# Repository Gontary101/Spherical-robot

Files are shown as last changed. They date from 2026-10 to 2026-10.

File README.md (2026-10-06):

# GYRA: rubber-tyred spherical robots inspired by the RT-G (Mk1 → Mk2 + learned control)

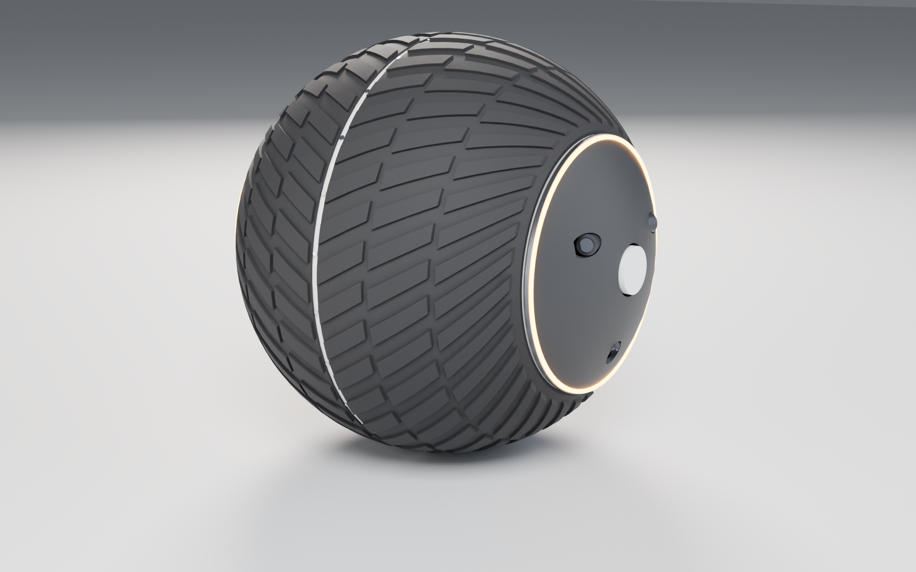
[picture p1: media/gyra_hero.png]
GYRA Mk1


This repo has three parts (the third is the Mk2 section below):

1. **A teardown of how the RT-G (Rotunbot/RotunBot) police robot actually works**, from
   the Zhejiang University paper behind it plus press and company sources:
   **[docs/01_RT-G_how_it_works.md](docs/01_RT-G_how_it_works.md)**
2. **GYRA Mk1**, a new design that keeps the RT-G's best idea (a wide rubber tyre
   rolling around a non-rotating sensor axle) and adds:
   * a **level sensor spine**, mechanically separate from the drive pendulum: the pods
     stay within 0.75° while the pendulum swings 46°;
   * a **scissored, counter-rotating CMG pair** that gives **pure roll torque**
     (stops lean-steer wobble) *or* **pure yaw torque** (turns on the spot at zero
     speed), with zero net momentum when idle;
   * an **equatorial internal ring-gear drive** (30:1) with **two anti-backlash
     pinions**;
   * a **self-locking worm lean drive** that holds a lean at zero power.

   Full spec: **[docs/02_GYRA_Mk1_design.md](docs/02_GYRA_Mk1_design.md)** ·
   simulation: **[docs/03_simulation.md](docs/03_simulation.md)** ·
   interactive 3-D viewer: **[docs/viewer/index.html](docs/viewer/index.html)**
   (open locally in a browser)

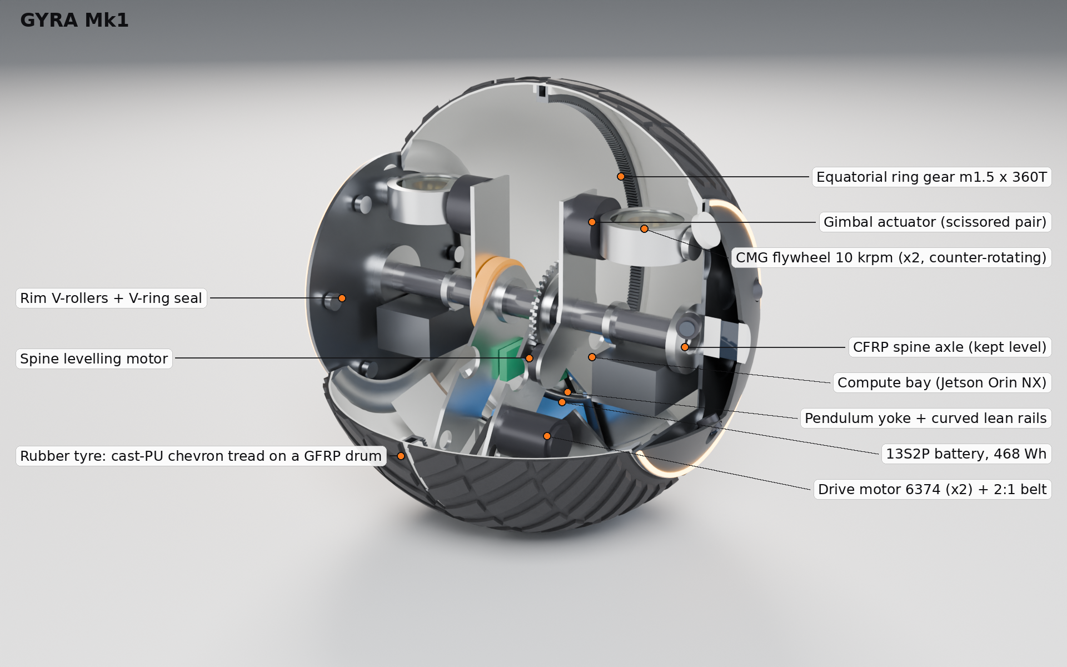
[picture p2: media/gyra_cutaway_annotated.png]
annotated cutaway


## Mk2: split differential tyre + learned control (latest)

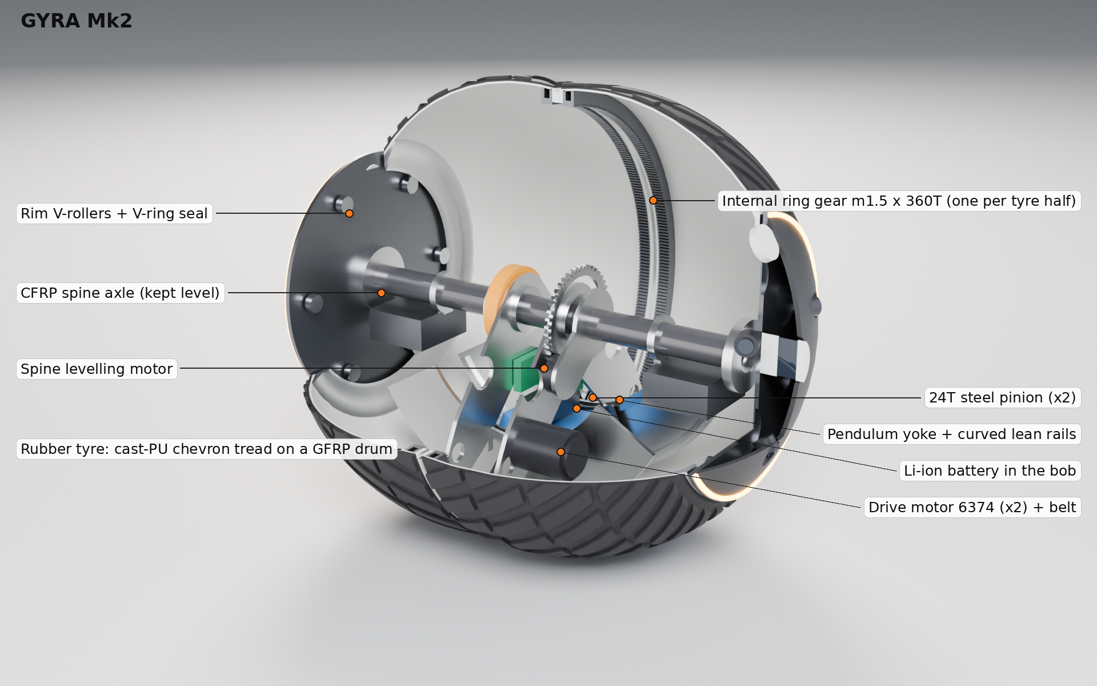
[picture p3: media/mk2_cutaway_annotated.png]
GYRA Mk2


Mk2 drops the CMGs. The tyre becomes **two independently driven halves whose crowns
are offset 50 mm outward**, so the robot stands on two contact patches and steers with
the torque *difference* between the halves. The freed mass goes into an 11 kg tungsten
+ 936 Wh bob, and the pendulum can now swing a full 360°. On top of this sit two
**asymmetric-PPO policies** trained in MuJoCo on the CAD-derived model:
* a **locomotion/teleop policy**: a residual over the classical loop, fed by IMU and
  encoders;
* an **autonomous navigator**: pod LiDARs with the real blind wedge, stereo depth,
  drifting odometry.

| | RT-G | Mk1 | **Mk2 + learned control** |
|---|---|---|---|
| turn in place | can't | 9°/s | **176°/s** (~20×) |
| 6 m/s turn at 0.6 rad/s | — | — | **stable, 7° roll** (classical loop falls) |
| falls, random commands + randomised physics + shoves | — | — | **8 %** (classical: 67 %) |
| sensor-pod pitch while accelerating | ≈ 40° | 0.75° | **0.39°** |
| grade (sim) | 10° tested | 10° | **14°** |
| battery | 2.4 kWh @ 160 kg | 468 Wh @ 41 kg | **936 Wh @ 45 kg** |
| autonomous navigation, 100 random maps | claimed | — | **79 % success, 2 % collisions, 1.35 m/s** (VFH baseline: 72 %, 11 %, 0.86 m/s) |

What does *not* get 10× better, and why (gravity-limited grade and acceleration), is
covered in [docs/04](docs/04_mk2_research_and_bounds.md). Full numbers:
[docs/07_scorecard.md](docs/07_scorecard.md) · design: [docs/05](docs/05_GYRA_Mk2_design.md) ·
learning: [docs/06](docs/06_learned_control.md) · 3-D viewer: [docs/viewer/mk2.html](docs/viewer/mk2.html)

| Learned locomotion vs classical | Mk2 classical benchmark |
|---|---|
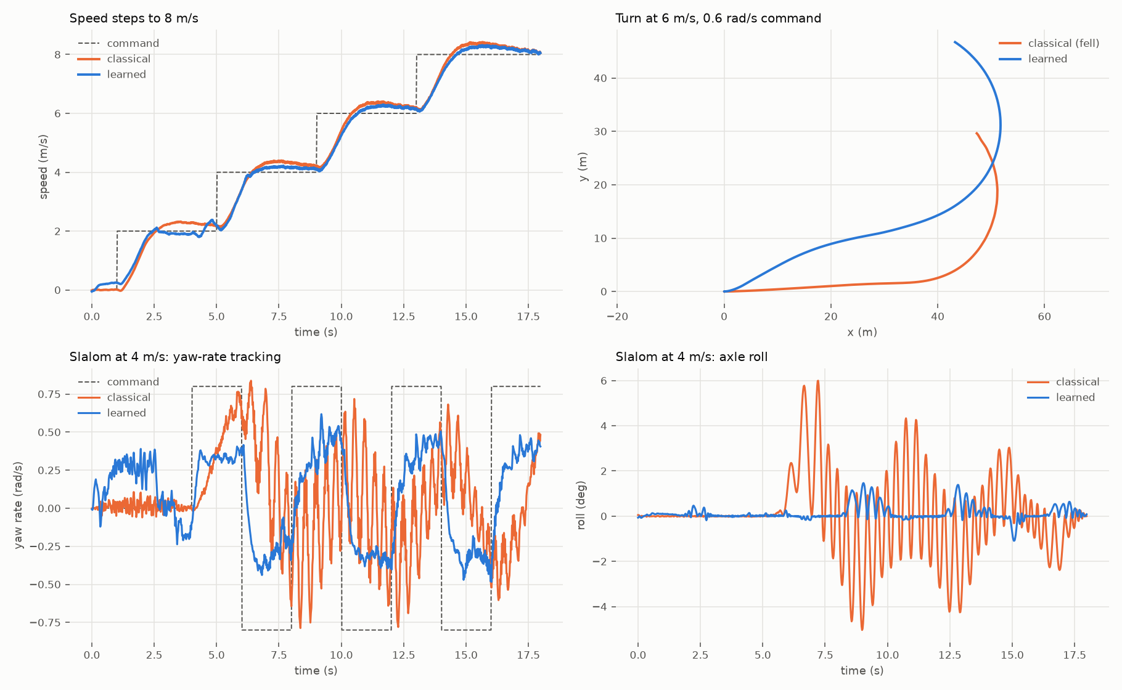
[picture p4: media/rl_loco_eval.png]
rl
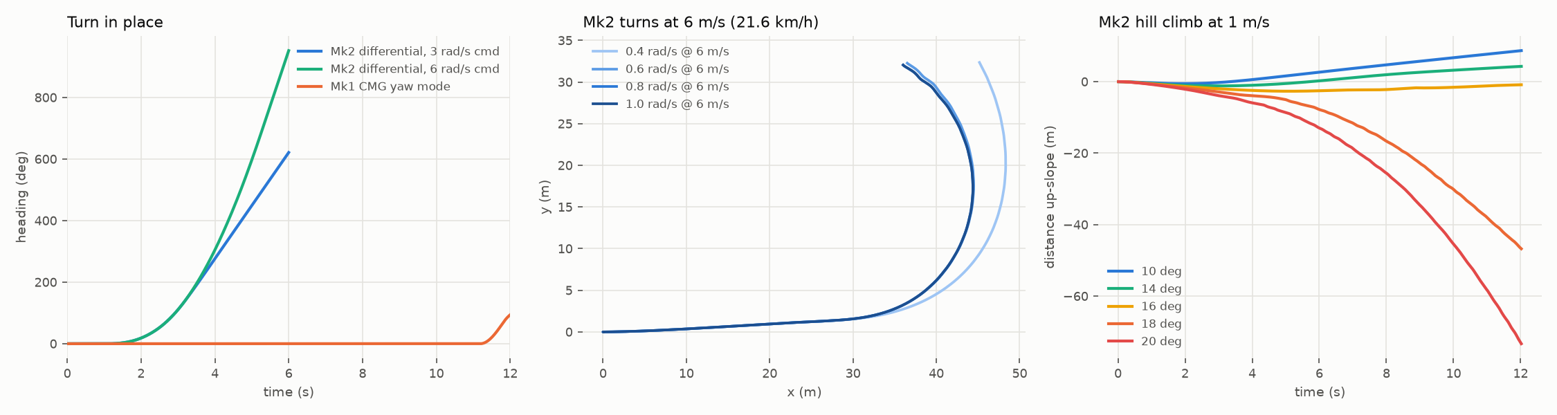
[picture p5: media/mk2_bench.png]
mk2
|  |  |

---

## The short version of "how RT-G works"

* The **central rubber shell** (fibre-reinforced rubber with a tread, 27.6 kg) is the
  only part that rolls. **The side pods are bolted to the main shaft**, so cameras,
  LiDAR and GNSS see out directly; there's no transparent hull.
* A motor on the internal frame turns the shell. Its reaction torque **lifts a 73 kg
  pendulum** (battery inside), and gravity does the driving. Grade and acceleration are
  limited by m·g·L of the pendulum, not by the motor.
* **Steering = leaning.** A second motor swings the pendulum sideways. The spinning
  shell precesses toward the low side, like a rolling coin, so the turn radius grows
  with v².
* A **42 cm momentum wheel** with its axis along the direction of travel only damps
  roll wobble. That's what let the RT-G reach 10 m/s.
* Correction to the "axis stays stable" idea: the pods are held level only by gravity,
  and **they pitch with the pendulum** when the robot accelerates, brakes or climbs.
  GYRA fixes this.

## GYRA Mk1 at a glance (all derived from the CAD model)

| | | | |
|---|---|---|---|
| Diameter | **600 mm** | Mass | **41.4 kg** (CoM 59 mm below centre) |
| Top speed | **6.4 m/s** (23 km/h) | Drive | 2 × 6374 BLDC → belt → ring gear, **30:1** |
| Grade | **10°** demonstrated in sim (13.6° static) | Lean torque | **11.2 N·m** sustained, + **18.5 N·m** CMG burst |
| Turn radius | 1.3 m @ 1 m/s · 5.8 m @ 2 m/s (sim) | Turn in place | **yes** (CMG yaw mode) |
| Sensors | 2 × Livox Mid-360, 6 × GS cameras (0.56 m stereo baseline), dual-antenna RTK | Compute | Jetson Orin NX 16 GB |
| Battery | 468 Wh, ~4 h / 45 km @ 3 m/s | Water | floats at 41 % draft, chevron tread paddles |
| Parts | 89 | Interferences | **0 across 45 mechanism poses** (B-rep check) |

| Exploded | Section through the drive plane |
|---|---|
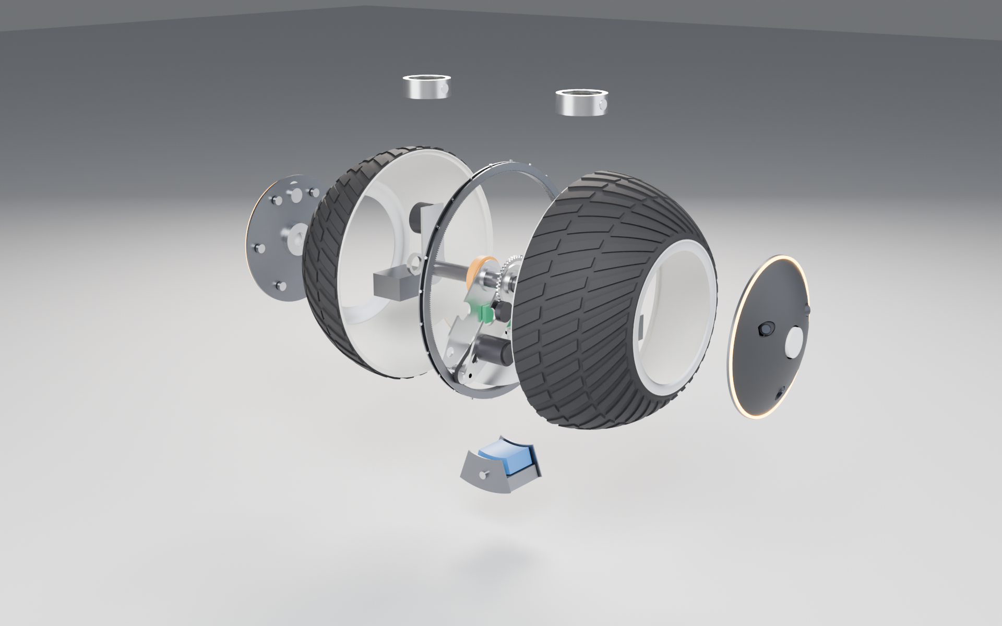
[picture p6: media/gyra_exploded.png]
exploded
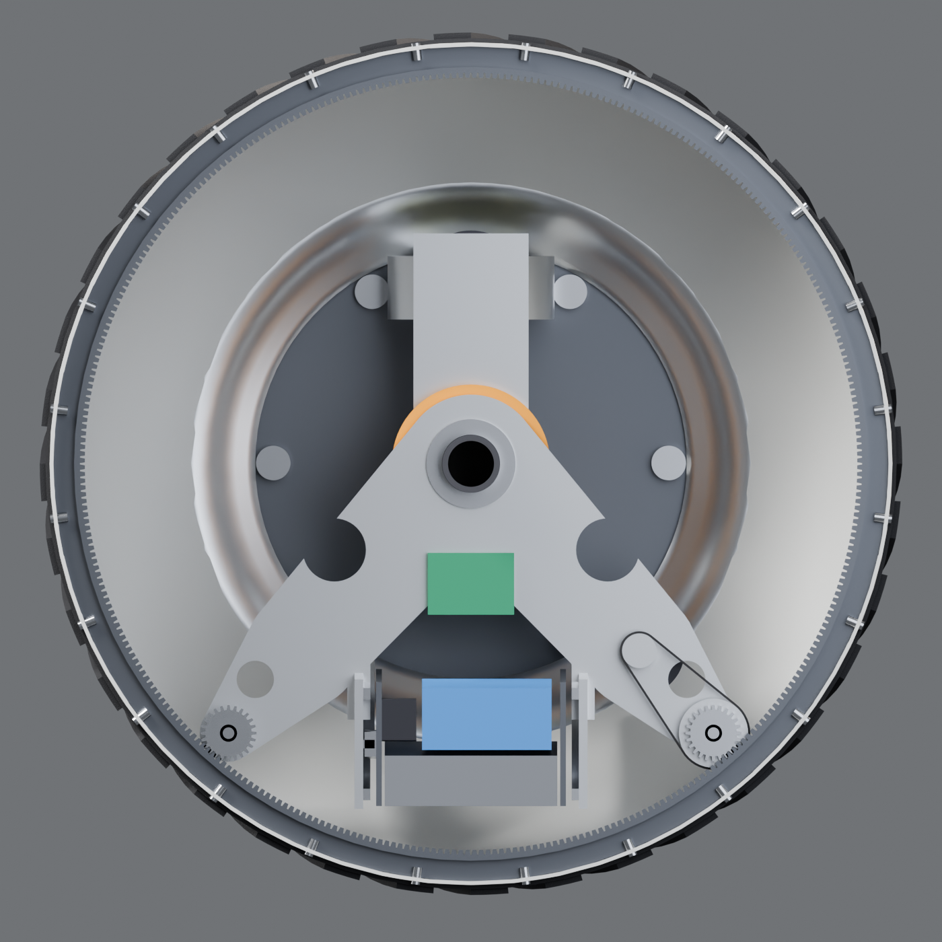
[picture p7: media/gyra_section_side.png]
section
|  |  |
| **Leaning into a turn** | **X-ray** |
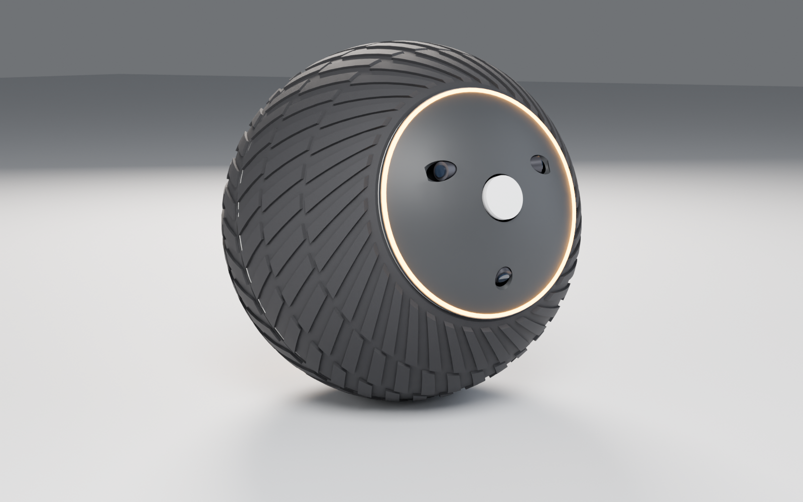
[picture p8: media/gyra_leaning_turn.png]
lean
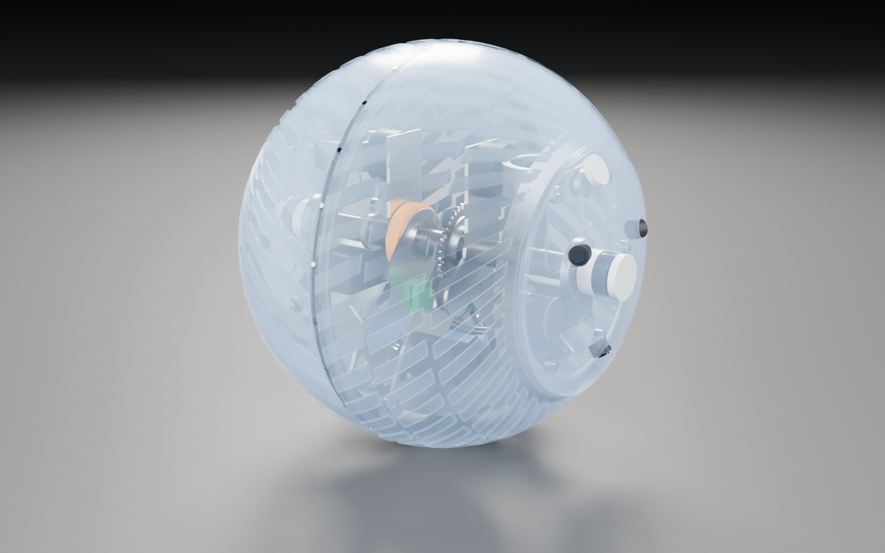
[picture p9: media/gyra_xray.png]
xray
|  |  |

### Simulation highlights (MuJoCo, model generated from the CAD inertias)
| Lean-steer at 2 m/s: CMG off vs on | Turn in place at zero speed |
|---|---|
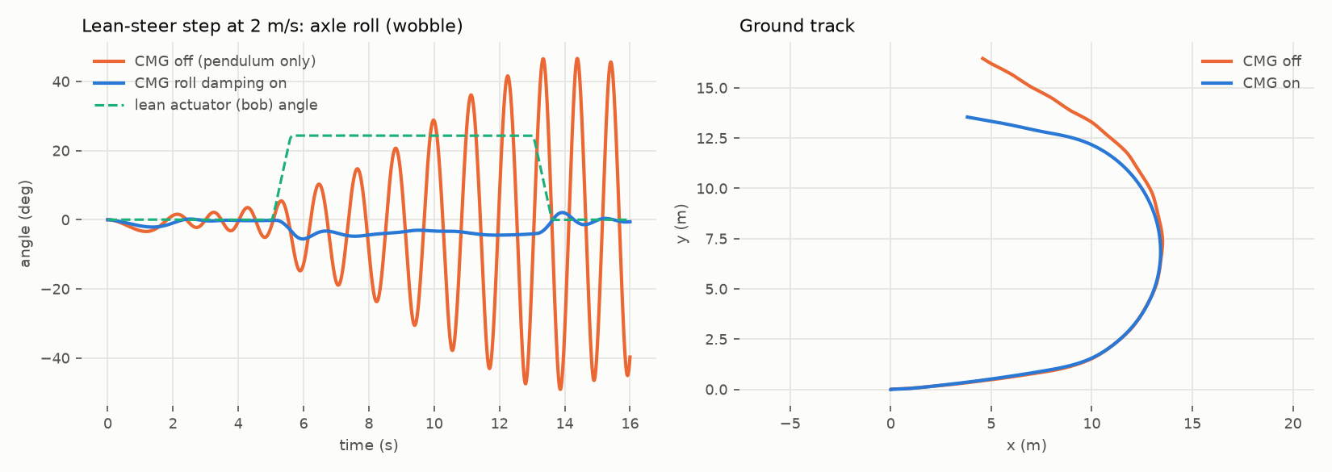
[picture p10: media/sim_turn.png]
turn
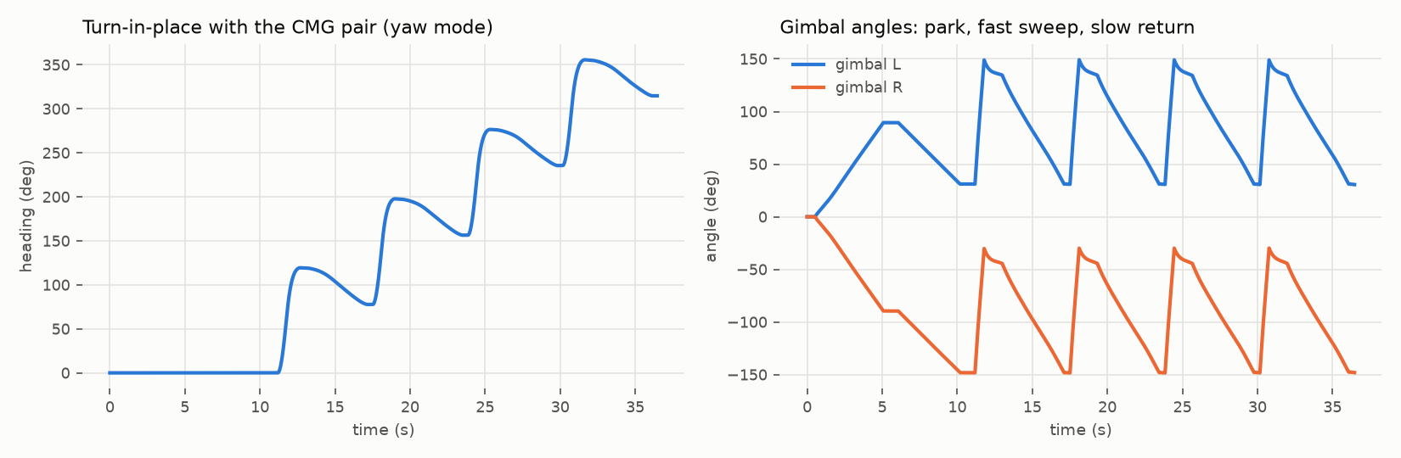
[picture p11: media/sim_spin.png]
spin
|  |  |

## Repository layout
```
cad/gyra2_cad.py         Mk2 parametric CAD (split tyre) -> cad/out2/
sim/gyra2_model.py       Mk2 MuJoCo model + motor torque-speed model
sim/gyra2_sim.py         Mk2 classical controller + benchmark
rl/loco_env.py           locomotion env (sensor-realistic actor obs, privileged critic, domain randomisation)
rl/nav_env.py            navigation env (pod-LiDAR blind wedge, stereo depth, drifting odometry)
rl/ppo.py, vec_env.py    asymmetric PPO + subprocess vector env
rl/train_*.py, eval_*.py training + evaluation; rl/runs/{loco,nav}/ deployed policies + eval.json
calc/scorecard.py        RT-G vs Mk1 vs Mk2 table from all result files
cad/params.py            single source of truth for dimensions
cad/gyra_cad.py          parametric CadQuery model → STEP / STL / mass properties / interference check
cad/export_glb.py        → cad/out/gyra_mk1.glb
cad/out/                 gyra_mk1.step (coloured assembly), stl/, glb, mass_properties.json, interference_report.json
calc/sizing.py           closed-form sizing from the CAD mass properties → calc/out/sizing.json
sim/gyra_model.py        MJCF generator (CAD inertias → MuJoCo)
sim/scenarios.py         closed-loop experiments → sim/out/summary.json, media/sim_*.png
render/render_gyra.py    Blender Cycles renders (hero, cutaway, x-ray, exploded, sections, poses)
render/annotate.py       visibility-checked call-out labels
render/build_viewer.py   self-contained three.js viewer → docs/viewer/index.html
docs/                    research report, design spec, simulation report
```

## Reproduce
```bash
pip install cadquery mujoco numpy scipy matplotlib trimesh pillow torch
python cad/gyra_cad.py --check        # CAD, exports, mass properties, 45-pose interference check
python cad/export_glb.py
python calc/sizing.py
python sim/scenarios.py
BLENDER=/path/to/blender render/render_all.sh
python render/annotate.py media/gyra_cutaway.png media/gyra_cutaway_annotated.png
python render/build_viewer.py            # Mk1 viewer;  `mk2` for the Mk2 viewer
# Mk2 + learned control
python cad/gyra2_cad.py --check && python cad/export_glb.py out2
python sim/gyra2_sim.py
python rl/train_loco.py --steps 4e6 && python rl/eval_loco.py
python rl/train_nav.py --loco rl/runs/loco/best.pt --steps 7e5 && python rl/eval_nav.py
python calc/scorecard.py
```
Tested with CadQuery 2.8 / OCCT 7.9, MuJoCo 3.15, Blender 4.2 LTS.

## Status
Mk1 is a **concept-level CAD and simulation design**, not yet built. Gears use
trapezoidal tooth approximations. Purchased parts are modelled as envelopes with their
real masses. The main open items are in §7 of the design doc: grade capability, seal
validation and flywheel spin-down/burst testing.

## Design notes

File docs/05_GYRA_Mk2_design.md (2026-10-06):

# GYRA Mk2: split tyre, differential drive, learned control

Mk2 follows from the analysis in [`04_mk2_research_and_bounds.md`](04_mk2_research_and_bounds.md).
It drops the CMG pair and splits the tyre into two independently driven halves with
outward-offset crowns. The freed mass becomes a tungsten + battery bob. Everything
below is generated: CAD → mass properties → MuJoCo model → controllers/policies.

| | |
|---|---|
| CAD | `cad/gyra2_cad.py` → `cad/out2/` (STEP, STL, mass properties, interference report) |
| Physics model | `sim/gyra2_model.py` (inertias read from the CAD), motor torque-speed model |
| Classical baseline | `sim/gyra2_sim.py` |
| Learned control | `rl/` (asymmetric PPO), see [`06_learned_control.md`](06_learned_control.md) |

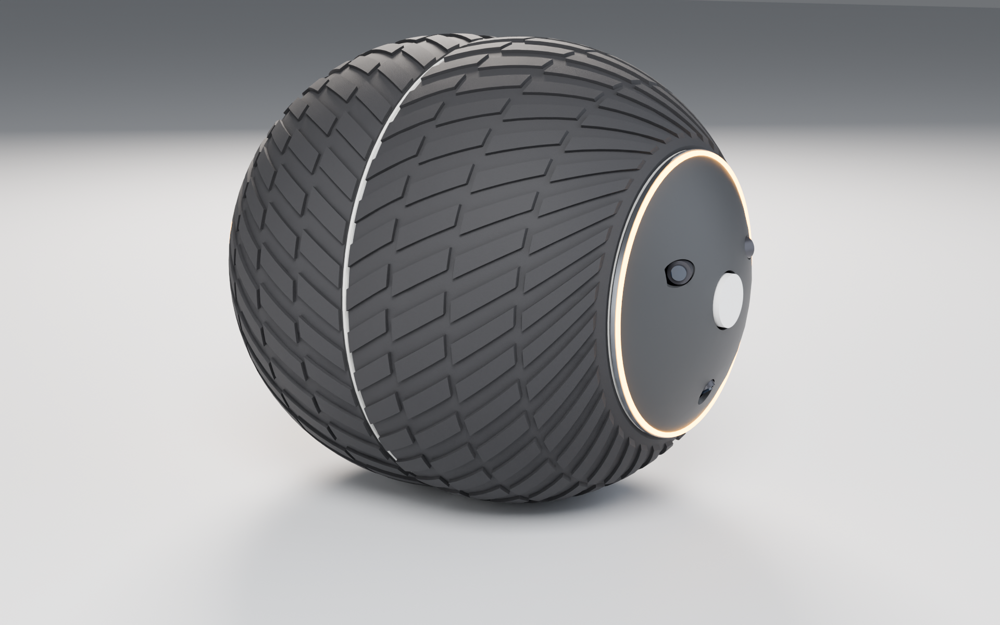
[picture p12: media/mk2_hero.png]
Mk2 hero


| Annotated cutaway | Front section (twin crowns, twin ring gears, seam slewing ring) |
|---|---|
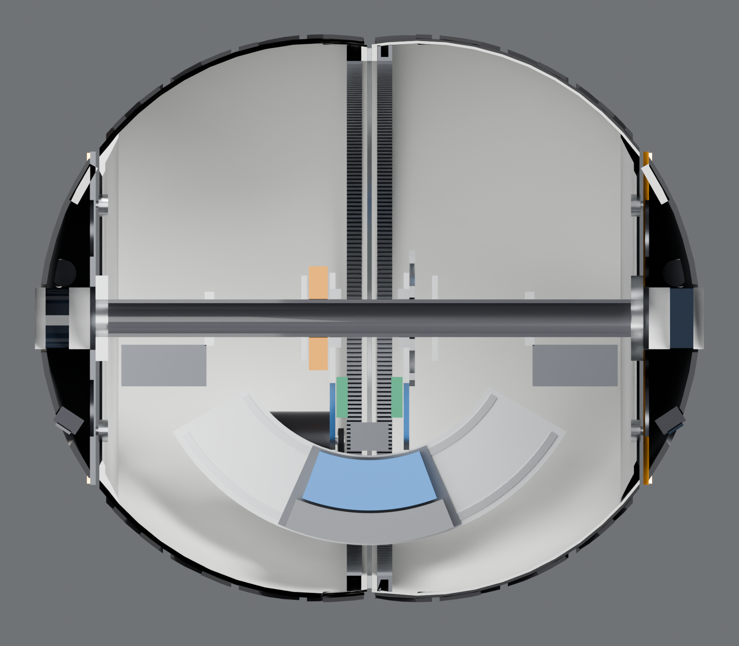
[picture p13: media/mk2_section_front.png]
section
| cutaway |  |
| **Pendulum 60°, bob 35° (driving + counter-leaning)** | **Exploded** |
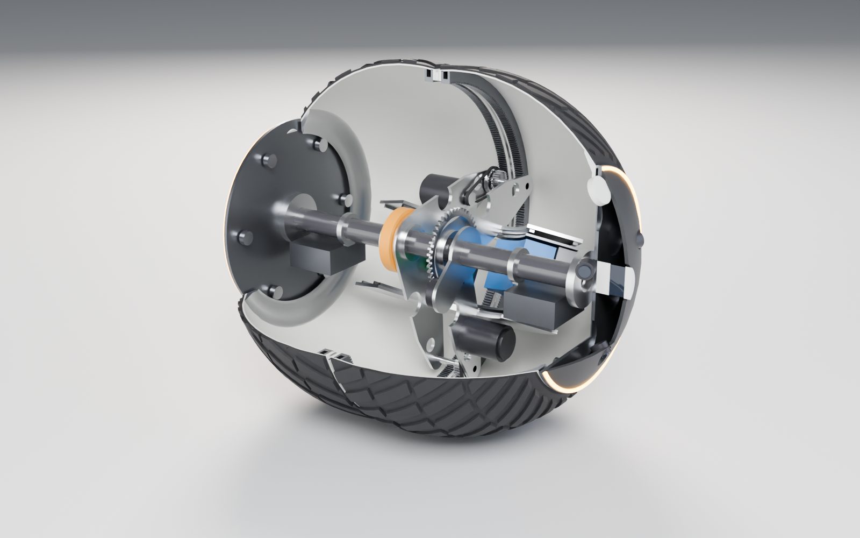
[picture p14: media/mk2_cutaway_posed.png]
posed
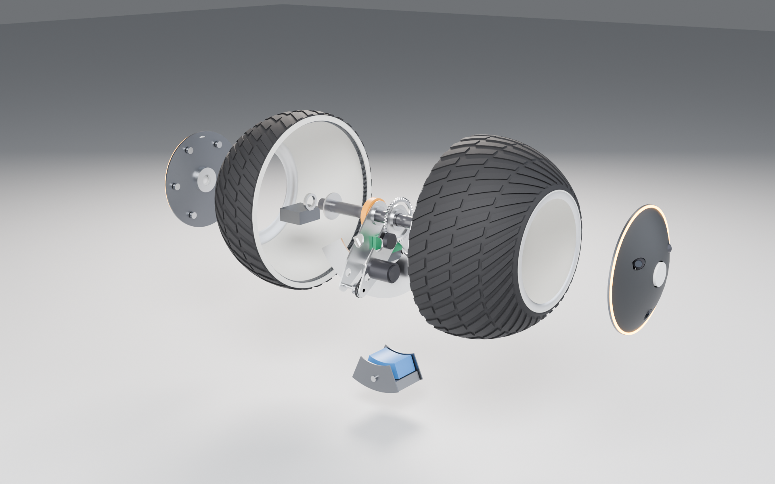
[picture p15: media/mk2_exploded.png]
exploded
|  |  |

Interactive: [`docs/viewer/mk2.html`](viewer/mk2.html).

## 1. What changed vs Mk1 and why

| | Mk1 | Mk2 | reason |
|---|---|---|---|
| Tyre | one drum, one ring gear | **two halves**, each with its own ring gear, joined by a wire-race slewing ring | differential drive: continuous yaw torque at any speed |
| Crown profile | single sphere | each half = sphere centred at y = ±50 mm → **two contact patches 100 mm apart** | passive roll stiffness M·g·d; no wobble mode at rest |
| Steering | lean + precession, CMG roll/yaw | **differential torque** + counter-lean bob | 20-40× faster spin, tighter high-speed turns |
| CMGs | 2 × 1.5 kg flywheels + 2 gimbal actuators | **removed** | twin crown handles roll and the differential handles yaw; 6.5 kg freed |
| Bob | 8.4 kg lead + 468 Wh, ±30° | **11 kg W-Ni-Fe + 936 Wh (13S4P)**, ±40° | more m·L (grade) and 2× energy |
| Pendulum travel | ±75° hard stop | **360° free**: nothing of the spine is in its swept volume | full m·g·L at 90°, no stop impacts |
| Compute | spine bay | on the pendulum (adds ballast) | better m·L |
| Drive ratio | 30:1 | **24:1** (15:1 gear × 1.6:1 belt) | 9.4 m/s no-load at 48 V |
| Width × height | 600 × 600 mm | 700 × 600 mm (each half keeps R 300) | |
| Mass | 41.4 kg | 45.1 kg | CoM 91 mm below centre (Mk1: 59 mm) |

**Interference check:** 0 collisions over pendulum pitch 0/±60/±120/180° × bob lean
0/±40°.

## 2. How the differential works with a pendulum drive

Both motors are mounted on the pendulum yoke. The front motor drives the left half,
the rear motor the right half.

* **Sum of torques** → reaction on the yoke → the pendulum swings → forward drive
  (gravity-limited: m·g·L = 39.7 N·m).
* **Difference of torques** → cancels inside the yoke (no pendulum swing) → a pure
  yaw couple (F_R − F_L)·d at the two contact patches. It is **not limited by the
  pendulum**, only by motor torque (82 N·m stall per half) and pivot friction.

## 3. Results from the physics model (classical controller)

| metric | Mk1 (sim) | **Mk2 (sim)** | gain |
|---|---|---|---|
| Turn in place, mean yaw rate | ~9°/s (CMG ratchet) | **163°/s** (3 rad/s cmd) · **258°/s** (6 rad/s cmd) | **18-29×** |
| Turn-in-place drift | 7 cm per 315° | **1 mm** | ~70× |
| Sensor pitch, 0 → 3 m/s → 0 | 0.75° | **0.39°** | 2× (≈ 120× vs RT-G-style pods) |
| Max grade (sim, 1 m/s) | 10° | **14°** (16° stalls) | 1.4× |
| Max stable speed | 6.4 m/s (motor) | **8.5 m/s** (9.0 m/s peak) | 1.3× |
| Turn radius at 6 m/s | ~48 m (lean only, predicted) | **17.9 m** with the classical loop | 2.7× |
| Battery | 468 Wh | **936 Wh** | 2× |

The classical yaw loop **oscillates at high speed**. Above roughly 0.5 rad/s at 6 m/s,
the yaw, roll and precession couplings make the hand-tuned loop diverge, even though
the tip-over bound allows about 4.5 m/s² of lateral acceleration. That is the gap the
learned locomotion policy targets.

Mk2 benchmark

## 4. Honest limits
* **Grade** stays gravity-bound: static m·L/(M·R) gives 17.4°, and 14° is
  demonstrated. No internal-drive sphere gets 10× here (see doc 04).
* **Width** grows by 100 mm. The robot is still a closed, self-righting body: lying
  on a pod, its CoM sits 92 mm off the pod sphere's centre, which rights it.
* The **forward blind wedge** of the pod LiDARs gets slightly wider (the pods move
  out by 50 mm). The centre line is seen from about 2.0 m ahead. The navigation policy
  is trained with this blind wedge modelled.

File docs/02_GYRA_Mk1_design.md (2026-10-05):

# GYRA Mk1: design specification

**GYRA** (*gyro + gyrate*) is a 600 mm, 41 kg, amphibious, rubber-tyred spherical robot.
It keeps what makes the RT-G work (a single wide rubber tyre that rolls around a
non-rotating sensor axle, driven by a pendulum) and adds four ideas the RT-G doesn't have:

1. a **level sensor spine** that is mechanically separate from the pendulum,
2. a **scissored, counter-rotating CMG pair** that does **roll** *and* **yaw**,
3. an **equatorial ring-gear drive** with dual anti-backlash pinions,
4. a **self-locking worm lean drive** (lean held at zero power) paired with the fast CMGs.

hero

---

## 1. Architecture: four coaxial bodies on one axle

```
        z ↑   x → (forward)    y ⊙ (left, along the axle)

  ┌──────────────── TYRE (rotates about y) ────────────────┐
  │ GFRP drum halves + cast-PU chevron tread               │
  │ equatorial internal ring gear m1.5 × 360T (joins halves)│
  │ aluminium rim rings with V-tracks at both edges        │
  └───────▲──────────────────────────────▲─────────────────┘
          │ 2 × 24T pinions (drive)       │ 6 V-rollers per side
  ┌───────┴───────── YOKE (pendulum) ─────┐  ┌────┴──────── SPINE (sensor axle) ────────┐
  │ hanger plates on 6908 bearings         │  │ CFRP axle Ø40 + 2 sensor pods          │
  │ 2 × 6374 BLDC → HTD belt 2:1 → pinions │◄─┤ levelling motor (spine ↔ yoke)         │
  │ cradle arc plates + curved rails/rack  │  │ CMG pair (gimbals ∥ y) + gimbal motors │
  └───────▲────────────────────────────────┘  │ compute bay, power/IMU bay, clockspring│
          │ curved rails, worm + pinion        └────────────────────────────────────────┘
  ┌───────┴──────── BOB ───────────────────┐
  │ 13S2P battery + 8.4 kg lead ballast     │   rides a ±30° arc about the x axis
  └────────────────────────────────────────┘
```

| Body | Joint (to its parent) | Mass (CAD) | CoM (mm) |
|---|---|---|---|
| Tyre | revolute **y**, on the spine's rim rollers | 11.31 kg | centre |
| Spine | — (free body) | 9.47 kg | (3, 9, 9) |
| CMG gimbals ×2 | revolute **y** at (0, ±170, 122) | 0.48 kg each | |
| Flywheels ×2 | revolute **z** (gimbal frame) | 1.50 kg each | |
| Yoke | revolute **y** on the axle (6908 bearings) | 5.74 kg | (2, 0, −129) |
| Bob | revolute **x** on the yoke's curved rails | 10.92 kg | (0, 0, −208) |
| **Robot** | | **41.39 kg** | **59 mm below centre** (self-righting) |

All masses, centres and inertia tensors come from the CadQuery model
(`cad/out/mass_properties.json`). The MuJoCo model is generated directly from them.

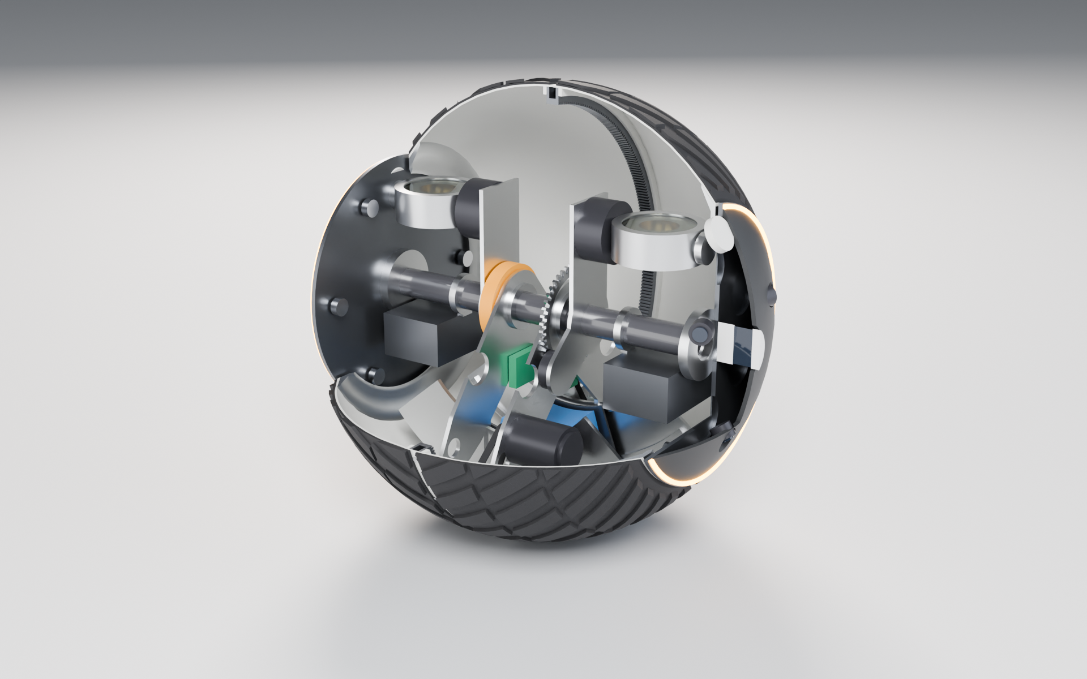
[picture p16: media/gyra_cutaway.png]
cutaway


---

## 2. The four new ideas

### 2.1 Level sensor spine (three coaxial bodies instead of two)
In the RT-G the pods are bolted to the shaft frame. The frame carries the drive motor,
so it pitches with the pendulum. In GYRA the **drive motors react against the yoke
only**. The **spine** (axle + pods + CMGs + compute) is a separate body that touches the
yoke through one small **levelling motor**. That motor holds the spine level (IMU on
the spine, PD loop), and its reaction torque goes into the heavy pendulum, which barely
notices it.

* Simulated 0 → 3 m/s → 0: the **pendulum swings to 46°**, the **sensor spine stays
  within 0.75°** (see `03_simulation.md`).
* Bonus: the levelling motor can **nod** the spine on purpose (±20°) to sweep the LiDARs
  for denser 3-D scans, or to look up stairs or down slopes.
* The spine is balanced: its CoM sits 9 mm from the axle, so the levelling torque is
  tiny (< 2 N·m in the drive test).
* Power and data cross the spine/yoke joint through a **clockspring** (flat wound
  ribbon, like a car's steering-wheel airbag reel). A hard stop at ±75° pendulum pitch
  means the reel never needs more than one turn. That's cheaper, quieter and more
  reliable than a slip ring.

### 2.2 Scissored CMG pair: one mechanism, two jobs
Two 100 mm steel ring flywheels spin in **opposite** directions at 10 000 rpm
(h = 2.31 N·m·s each, 1.2 kJ stored each) inside sealed housings. Both gimbals turn
about **axes parallel to the axle**.

**Roll mode** (spin axes near vertical). The gimbals move in opposite directions
(scissor, γ_L = +γ, γ_R = −γ):

  H = h(sin γ, 0, cos γ) + h(sin γ, 0, −cos γ) = 2h sin γ · x̂ → torque on body = −2h cos γ γ̇ · x̂

That is a **pure roll torque** of up to **18.5 N·m** at 4 rad/s gimbal rate. That's more
than the bob's whole sustained lean authority (11.2 N·m), with zero cross-coupling into
pitch or yaw. **Net stored momentum is zero at γ = 0**, so the robot does *not* behave
like a gyroscope when the CMGs are idle. A single big momentum wheel (the RT-G approach)
would add unwanted precession on every turn.

**Yaw mode** (gimbals parked at γ_L = +90°, γ_R = −90°, spin axes horizontal fore-aft,
still zero net momentum). The gimbals now sweep **together** by δ:

  H = (0, 0, −2h sin δ) → torque on body = +2h cos δ δ̇ · ẑ

That is a **pure yaw torque** of up to **18 N·m**. It beats the tyre's pivot friction
(≈ 8.5 N·m for a 35 mm contact patch), so **GYRA can spin on the spot at zero speed**.
Pendulum spheres, including the RT-G, can't do this. Each fast sweep (120°) turns the
robot about 75-110°. A slow return (torque below stiction) resets the gimbals.
Simulated: **315° in 4 cycles with 6 cm drift**.

Roll mode buys you:
* **wobble suppression**: in the sim, lean-steering at 2 m/s diverges to ±45° roll
  with the pendulum alone, versus **±0.7° with CMG damping**;
* **instant turn-in**: it cancels the "wrong-way" reaction torque you get when the bob
  starts swinging;
* **fall/kerb recovery**: a 4 N·m·s roll impulse is enough to stop a side-tip from a
  kerb strike.

Sizing and safety: flywheel ring OD 100 / ID 50 / 30 mm, 4340 steel, rim speed 52 m/s
(very low for steel, so the margin to burst is above 10×). The housings are
aluminium cans with polycarbonate inspection lids. The gimbal actuators are CubeMars
AK70-10 class (the gyroscopic load at 2 rad/s body rate is 4.6 N·m, against 8 N·m
continuous). Spin motors are about 40 W; spin-up takes about 60 s; idle drag is about
12 W per wheel.

### 2.3 Equatorial ring-gear drive
The drum is made as two GFRP halves bolted through an **internal ring gear at the
equator** (m 1.5, 360 T, Ø540 pitch, PA66-GF30 segments, I-section web). The bolts sit
in the tread's centre groove. Two **24 T steel pinions** on the yoke engage it at ±42°
from bottom dead centre. Each is driven by a **6374-class 150 KV BLDC** through a
**2:1 HTD belt**:

* overall ratio **30:1** with the final stage at the largest possible radius, so tooth
  loads are low (28.6 N·m ÷ 0.27 m ≈ 106 N at the mesh);
* two pinions **pre-loaded against each other** remove backlash (the motors apply
  opposing bias torque at standstill), so there's no clunk when the pendulum
  reverses;
* redundancy: one motor alone can still drive at full pendulum-limited torque, since
  0.53 N·m per motor is needed against 3.8 N·m peak available;
* top speed ≈ **6.4 m/s (23 km/h)** at 48 V; drive torque is pendulum-limited at
  **28.6 N·m**.

### 2.4 Worm lean drive + CMG = slow-strong / fast-light
The **bob** (13S2P battery and 8.4 kg of lead) rides **curved rails** on the yoke's
cradle along a **±30° arc about the x axis**, driven by a **self-locking worm** and a
pinion on a curved rack. It provides a **sustained lean torque of 11.2 N·m with zero
holding power**. The worm can't back-drive, so a turn costs energy only when the lean
*changes*. It is slow by design (45°/s); the CMG pair supplies the bandwidth.

---

## 3. Key numbers (from `calc/sizing.py`, all derived from CAD mass properties)

| | |
|---|---|
| Diameter / tyre width | 600 mm / 470 mm (tyre covers ±51.6° latitude) |
| Mass | 41.4 kg (tyre 11.3, pendulum 16.7, spine + CMGs 13.4) |
| CoM below centre | 59 mm (self-righting from any orientation) |
| Pendulum m·L | 3.02 kg·m (L_eff = 181 mm) |
| Max pendulum drive torque | 28.6 N·m (pitch stop 75°) |
| Drive ratio / top speed | 30:1 / **6.4 m/s (23 km/h)** |
| Max acceleration | 1.9 m/s² |
| Grade | **10° demonstrated in sim** (13.6° static limit) |
| Step | 8 mm static; ~130 mm dynamic (scaled from RotunBot's 17 cm @ R 0.4 m) |
| Sustained lean torque (bob ±30°) | 11.2 N·m |
| CMG pair roll / yaw torque | 18.5 N·m / 18 N·m (4 rad/s gimbal) |
| Turn radius (bob only) | 1.3 m @ 1 m/s · 5.3 m @ 2 m/s · 12 m @ 3 m/s · 48 m @ 6 m/s |
| Turn in place | yes, ~75-110° per CMG sweep |
| Flotation | floats with 41 % of the diameter submerged (246 mm draft), 72 kg reserve buoyancy |
| Battery / endurance | 468 Wh (13S2P 21700) / ~4.2 h, ~45 km at 3 m/s |

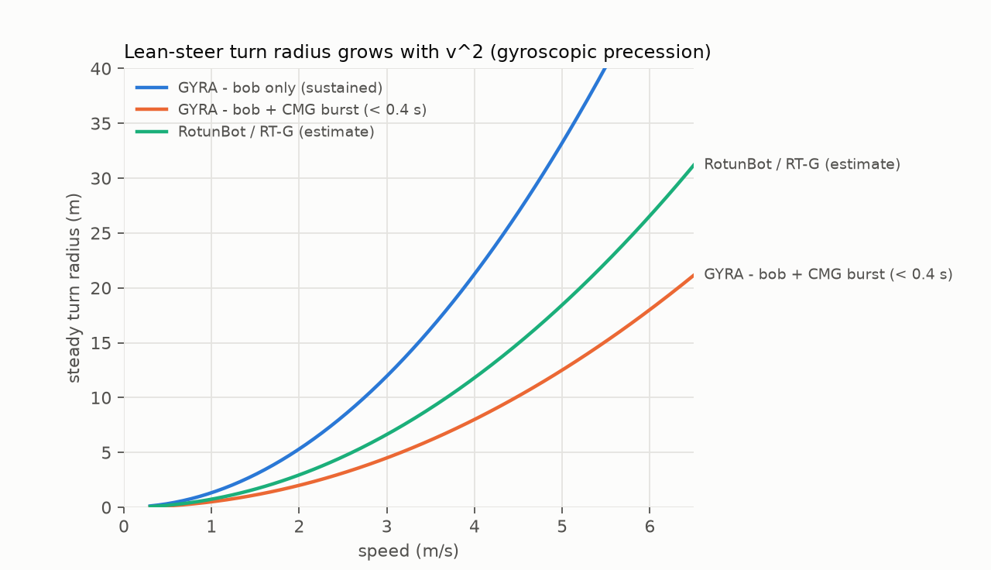
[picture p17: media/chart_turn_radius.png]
turn radius


---

## 4. Subsystem details

### Tyre
* **Drum**: two 2.5 mm GFRP spherical zones (|y| ≤ 235 mm). Each is laid up on a male
  plug and flanged at the equator for the ring gear.
* **Tread**: cast polyurethane, Shore 70A, 3 mm base + 4 mm chevron lugs (36 pitches ×
  3 rows per side, mirrored, half-pitch staggered). The chevron self-cleans mud and
  works as **paddles in water**. The 10 mm centre groove hides 24 × M5 equator bolts.
* **Rims**: 6061 rings bonded into each tyre edge, with a 90° V-track at r = 150 mm.
  Six eccentric-mounted V-rollers per pod carry the tyre (like a HepcoMotion PRT ring
  slide), so the pods can be **full rim size (Ø352)** without a huge thin-section
  bearing. A Forsheda **V-ring seal** at the 4 mm tyre/pod gap gives IP67.

### Spine
* **Axle**: CFRP tube Ø40/32, clamped into both pod plates. It carries the pendulum
  loads (≤ 1 kN dynamic).
* **Pods** (×2): 6 mm aluminium plate with lightening pockets, a 6 mm PA12 MJF shield
  (spherical cap, same R 300 as the tyre so the robot stays a sphere), and these
  sensors:
  * **Livox Mid-360** LiDAR on the axle line (360° × 59° FOV around the axle: sees
    forward, up, back and the ground on its side),
  * **3 global-shutter cameras** per pod: front (18° toe-out), rear, and ground/near-field.
    The two front cameras form a **stereo pair with a 0.56 m baseline**,
  * **u-blox ZED-F9P** antenna under a radome on each pod. With two antennas
    0.49 m apart you get **dual-antenna RTK heading**,
  * an amber **status light ring** at the pod rim.
* **Forward blind wedge**: the tyre (470 mm wide) blocks inward-looking rays. Pod
  sensors at y ≈ ±285 mm see the centreline from about 1.1-2.3 m ahead. Closer
  obstacles are tracked from the map built as they approach, and in-place yaw sweeps
  give a full look-around. (A radar *through* the non-metallic tyre is a Mk2 research
  item.)
* **Bays** below the axle (outside the pendulum's swept volume): left holds a Jetson
  Orin NX 16 GB plus carrier; right holds power distribution, a 9-axis IMU and radios.
* **Levelling motor**: pancake BLDC with a planetary reduction, pinion on a POM gear on
  the yoke hub.
* **Clockspring** on the −y side between the spine bracket and the yoke hub.

### Yoke & bob
* Hanger plates (6061, 6 mm) on 6908-2RS bearings carry both motor bosses and both
  pinion shafts. The shafts are supported at both ends.
* The cradle's arc plates (y-z sectors, ±50°) carry two curved V-rails each and one
  curved rack.
* Bob: lead casting (r 203-238 mm) plus a 13S2P 21700 pack (468 Wh) plus the worm
  gearmotor, all on a carriage with four V-rollers per side.
* The ESCs (2 × ODrive S1 class) sit on the inner faces of the hanger plates.

### Swept-volume design rule
Every pendulum part lives inside |y| ≤ 157 mm. Every spine part is either **outside**
that slab or **inside** r < 106 mm of the axle. The CMGs sit above the axle, and the
pendulum's ±75° stop keeps it out of the top sector. **`cad/gyra_cad.py --check`
verifies this with real B-rep booleans across 45 poses** (pitch −75…75°, lean ±30°,
gimbals 0 / ±90 / ∓60°): **0 interferences**.

---

## 5. Bill of materials (prototype, single unit, estimated USD)

| Item | Qty | Part / class | ≈ USD |
|---|---|---|---|
| Drive motors | 2 | 6374 150 KV outrunner | 140 |
| Drive controllers | 2 | ODrive S1 | 300 |
| Gimbal actuators | 2 | CubeMars AK70-10 | 900 |
| Levelling actuator | 1 | AK60-6 or GBM5208 + planetary | 250 |
| Flywheels + spin motors | 2 | 4340 ring (machined) + 40 W BLDC + ESC | 450 |
| LiDAR | 2 | Livox Mid-360 | 1500 |
| Cameras | 6 | IMX296 global shutter, M12 lenses | 360 |
| GNSS | 2 | u-blox ZED-F9P + patch antennas | 500 |
| Compute | 1 | Jetson Orin NX 16 GB + carrier | 900 |
| IMU | 1 | industrial 9-axis (e.g. Bosch BMI088 + mag) | 60 |
| Battery | 1 | 13S2P 21700 + smart BMS | 320 |
| Ballast | 1 | lead casting 8.4 kg | 60 |
| Tyre | 1 | GFRP drum (plug, mould, layup) + PU tread cast | 1400 |
| Ring gear | 1 | PA66-GF30, 6 segments (printed or water-jet) | 200 |
| Structure | — | water-jet 6061 plates, CFRP axle, MJF PA12 shields | 700 |
| Bearings, rollers, rails, seals, worm, belts | — | | 400 |
| Clockspring, wiring, connectors, fasteners | — | | 250 |
| **Total** | | | **≈ 8.6 k** |

## 6. Assembly sequence
1. Spine core: slide the bays, brackets, levelling motor and clockspring onto the axle.
2. Slide the yoke hub bearings on, mount the drive trains and arc plates, and fit the
   bob on its rails.
3. Mount the CMG modules on the spine brackets (inner gimbal actuators).
4. Bolt the drum halves to the ring gear around the internals (pinions mesh through
   the open rims), then torque the equator bolts from outside through the tread groove.
5. Fit the pods. The rollers engage the rim tracks, set preload with the eccentric
   pins, then bolt the pod plates to the axle flanges and fit the V-ring seals.
6. Fit the pod shields and sensors.

## 7. Risks and what Mk2 should change
* **Grade (10°)** is the weak spot of every pendulum sphere. Mk2: move the compute and
  CMGs into the pendulum, or use denser ballast (tungsten), to raise m·L/(M·R) from
  0.24 to above 0.30 (≥ 17°).
* **High-speed turn radius** grows with v². The CMG gives short bursts only. A
  speed-scheduled lean controller plus braking into corners is required.
* **Pivot stiction** sets how much of each CMG sweep is kept. Characterise it on real
  surfaces.
* **Flywheel containment** is low risk (52 m/s rim) but still needs a burst and
  spin-down test.
* **Sealing** of a 352 mm rotary joint: V-ring plus a labyrinth. Validate with a
  dunk test.

Full CAD: `cad/out/gyra_mk1.step` (89 parts, coloured) · `cad/out/gyra_mk1.glb` · `cad/out/stl/`.

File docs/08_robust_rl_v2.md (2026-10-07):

# GYRA Mk2: learned control v2, built to work anywhere

v1 (doc 06) learned to drive on flat ground with pushes, and to navigate a random-obstacle
arena. v2 rebuilds both policies and their training stack with three goals:

* hold up on any surface and under any disturbance the robot is likely to meet;
* use production-style architecture, rewards, curriculum and evaluation;
* keep simulation honest: what the robot collides with is exactly what its sensors see and
  what the renders show.

| | v1 | v2 |
|---|---|---|
| Ground | flat plane (+ gravity-tilt slopes) | procedural heightfields: hills, rough + potholes, curbs/steps/ditches, ramps to 15°, blended mixed terrain |
| World build | compiled once, obstacles moved at run time (**broken**, see §0) | **recompiled every episode** (~5 ms); obstacles are convex mesh geoms, pedestrians are mocap mesh bodies |
| Disturbances | pushes ≤ 250 N, friction 0.5-1.2 | pushes ≤ 350 N + yaw kicks, steady wind + gusts, friction 0.25-1.2 with **mid-run surface change**, payload ≤ 10 kg anywhere, tyre wear, per-motor strength 0.75-1.1, torque noise, 0-40 ms latency, IMU bias / misalignment / glitches |
| Locomotion actor | MLP on 4 frames (80 ms) | **1 s history → temporal conv encoder → latent + concurrent state estimator** → MLP |
| Losses | PPO | PPO + estimator regression + left/right **symmetry** loss; return normalisation; KL-adaptive LR with early stop |
| Curriculum | global, step-based | **per-environment** level (terrain, disturbances, speed range) moved up on clean episodes and down on falls, plus 15 % replay of easier levels |
| Navigation | 1 world type, Euclidean progress | 5 world families, pedestrians, **geodesic** progress, global-planner subgoal on a **stale prior map** (or none), sensor faults |
| Evaluation | random seeds | fixed-seed **robustness matrices** (16 locomotion, 12 navigation scenarios) against classical and v1 baselines |

## 0. A simulation bug, found and fixed

While making the video I checked that every obstacle's collision geometry matched its
rendered geometry, and found that **in v1's navigation world, obstacles never
collided**. The arena compiled 22 obstacle slots once, then moved and resized them per
episode by writing `geom_pos`/`geom_size`. MuJoCo keeps the static world body's
bounding-volume hierarchy and each geom's AABB from compile time. The broad phase
therefore never paired the tyres with a moved obstacle, and contacts were silently
missed. Only the walls, which never move, registered.

Consequences and fix:

* v1's reported navigation collision rate (2 %) only counted walls. The v1 numbers in
  doc 06 are wrong and are restated below, measured in the corrected world.
* Updating the AABBs alone is not enough (8 117 of 15 792 probe states still
  disagreed): the world-body BVH is also stale.
* v2 compiles a fresh world every episode (5 ms). Every static obstacle and wall is a
  convex mesh geom at its real pose, and moving obstacles are mocap bodies. MuJoCo
  collides convex meshes as their convex hull. All obstacles are convex and every
  input vertex is kept (asserted), so the collision shape is the mesh itself.
* The renderer builds every obstacle, wall, pole, pedestrian and the terrain from the
  geometry read back from the compiled model. It then re-casts 4 000 MuJoCo probe rays
  in Blender. Test mission: **max disagreement 0.11 mm over 3 830 rays** (float32
  rounding).
* Terrain lookups (`sim/terrain.height_at`) reproduce MuJoCo's heightfield vertex grid
  and triangulation exactly: max |ray − lookup| = 0.005 mm.

## 1. Locomotion v2

### World and robot randomisation (per episode, scaled by the env's curriculum level k)
| | range at k = 1 |
|---|---|
| terrain | 20 % flat, else one of hills (p95 slope 12°), rough + potholes, curbs/steps to 6 cm and ditches, ramps to 15°, smoothly blended mix |
| incline | 0-14° uniform slope in 40 % of episodes |
| friction | μ 0.25-1.2; 30 % of episodes switch surface mid-run (e.g. asphalt → ice) |
| robot | link masses ±10 %, CoM ±6 mm, payload 0-10 kg anywhere on the spine, tyre radius −1.5/+1 % |
| actuators | per-motor strength 0.75-1.1, 5 % torque noise, bob worm-drive 45-75°/s, latency 0-2 steps |
| pushes | 1 every 3 s on average, 50-350 N for 60-300 ms, with yaw kicks to ±40 N·m |
| wind | 0-40 N steady + Ornstein-Uhlenbeck gusts (σ 10 N, τ 1 s) |
| IMU | gyro noise 0.02 rad/s + bias to ±0.03 rad/s, mounting error to ±1.5°, rare glitch frames |
| operator | steps or 0.5-1.5 s ramps every 1.5-5 s: stop, spin, straight, arcs (lateral accel ≤ min(4, 0.6 μ g), 20 % unconstrained); speed range 2 → 8.5 m/s with k |

### Policy
* **Actor:** 50 × 18 proprioceptive frames (1 s) → 3-layer temporal conv → 64-d latent
  → linear **estimator** (body velocity, local slope, friction, payload, wind, motor
  strength). [current frame, command, latent, estimate] → MLP 256-128-64 → residual
  torque/bob action on top of the classical controller, with **full authority**
  (±60 N·m sum, ±60 N·m differential, ±0.5 rad bob).
* **Critic:** estimator targets + privileged state (contacts, every randomised
  parameter, push/wind forces, true attitude and rates) + a 7 × 7 terrain height scan →
  MLP 512-256-128.
* **Deployable artifact:** one TorchScript module with the observation normaliser
  folded in (`rl/runs/loco2/actor.ts`).

### Reward (final v3.1; per step, every term logged separately)
Errors are measured against the **feasible reference** (sec. 2), not the raw operator command.

| term | weight | |
|---|---|---|
| speed tracking | +1.0 · exp(−e_v²/0.25) + 0.5 · exp(−e_v²/0.01) | coarse + fine kernels |
| yaw-rate tracking | +0.75 · exp(−e_ω²/0.25) + 0.5 · exp(−e_ω²/0.01) | |
| distance / heading hold | +0.5 · exp(−E_s²/0.0025) + 0.5 · exp(−E_ψ²/0.0025) | E = leaky (0.2/s) integrals of the along-track and heading errors: a persistent bias is never free |
| steady sensor platform | +0.25 · exp(−(ω_pitch² + ω_roll²)/0.25) | camera/LiDAR stability is the robot's selling point |
| spine attitude | −1.0 θ_pitch² − 0.5 θ_roll² | level in both axes |
| residual size | −0.02 \|a\|² | deviate from the classical loop only when it pays |
| action rate, smoothness | −0.02 \|Δa\|², −0.01 \|Δ²a\|² | |
| mechanical power | −4·10⁻⁴ Σ max(τω, 0) | |
| torque saturation | −0.3 · clipped torque / stall torque | |
| pendulum slosh | −0.01 ω_pend² | |
| bob near its stop | −0.5 max(\|bob\| − 0.6, 0) | |
| failure: **pod strike** (CAD pod geometry touches the ground), pendulum loop-over, spine > 34° | −20, episode ends | |

### Results
Final policy: **v3.1** (`rl/runs/loco31/best.pt`, `actor.ts`), fine-tuned from v3 (15M steps) for 9M steps.
Robustness on the CAD-exact Mk2.1 model, 16 scenarios × 24 episodes (`rl/eval_robust.py`):

| controller / hardware | falls | mean spine tilt | speed RMSE vs feasible ref |
|---|---|---|---|
| classical, Mk2 as built | 27.7 % | 0.99° | 0.48 m/s |
| v1 policy, Mk2 | 19.5 % | 0.89° | 0.46 m/s |
| v2 policy (15M), Mk2 | 16.8 % | 0.83° | 0.37 m/s |
| classical, Mk2.1 | 12.5 % | 0.26° | 0.46 m/s |
| **v3.1 policy, Mk2.1** | **1.8 %** (7 / 384) | **0.21°** | **0.33 m/s** |

The remaining v3.1 falls: 350 N lateral pushes 12.5 % (beyond the roll capacity of the hardware: even an ideal bob
lean cannot recover a 350 N × 0.3 s side push), 12° incline 12.5 %, rough ground 4 %; 13 of 16 scenarios have none.

Low-speed precision (`rl/precision_test.py`, flat, 4 seeds), which tight-space navigation depends on:

| | classical | v3 | **v3.1** |
|---|---|---|---|
| spin in place: heading error vs command | 73° | 31° | **0.8°** |
| spin in place: displacement | 1 cm | 21 cm | 10 cm |
| creep 0.3 m/s, 10 s: heading drift | 0.4° | 27° | 13° |
| hold still 6 s: heading / displacement | 0.3° / 2 cm | 12° / 43 cm | 9° / 31 cm |
| stop from 1 m/s: overrun | 84 cm | 63 cm | 57 cm |

How v3.1 came about: navigation exposed a yaw bias in v3 (−0.08 rad/s while "holding still"). Channel isolation
showed it came entirely from the differential-torque residual (switching it off gives 0.0005 rad/s), and it went
with the bob action pinned at ±1 in a self-reinforcing lean (the policy observes its own last action, so
leaned-left and leaned-right are both stable modes that still satisfy the symmetry loss). The σ = 0.5 tracking
kernels made such small persistent errors almost free. Integrated-error terms, roll penalty and residual cost fix
spinning and stopping; the classical controller's yaw integrator still holds better at a standstill, and the navigation
layer closes the heading loop at 10 Hz anyway.

## 2. Root-cause analysis of the remaining falls (why v2 plateaued)

At 15M steps v2 had the lowest tracking error and spine tilt, but its fall rate had
stalled (9.4 % mean over 16 scenarios, versus 10.2 % for v1 and 18 % for classical).
Rather than patch scenario by scenario, every fall was instrumented
(`rl/diagnose_falls.py`) and each suspected mechanism tested in isolation.

**What the falls are.** All of them, for every controller and in all seven failing
scenarios, are sideways roll-overs. Drive-torque saturation before a fall is ~0,
so the "pendulum torque limit" hypothesis was wrong.

**Mechanism 1: the pendulum spends roll stability.** On a 12° incline (to hold
position) or when braking from 6 m/s, the pendulum swings to 45-70°. The robot's roll
stiffness comes from its low CoM (CoM drop ∝ cos θ_pendulum) plus the twin-crown
stance, and the bob's lean axis tilts with the yoke. Large pendulum angles therefore
halve both the passive roll stiffness and the bob's authority. Traces show a growing
roll oscillation (−60° → +58° within 0.5 s) at exactly those moments. Longitudinal
and lateral capability are coupled: a **stability ellipse**, not independent limits.

**Mechanism 2: the only roll actuator is too slow.** The worm-driven bob (60°/s)
needs ~0.7 s to cross its range, which is comparable to the ~2 s rocking period. It
rate-saturates and arrives half a cycle late (roll +32° while the bob is still at
−15°), pumping energy into the oscillation. The feedback sign is correct; flipping
it falls at 16°.

**Mechanism 3: the simulation's failure definition was not physical.** "Fall" was
roll > 63°, and the tyre halves were full spheres. Per the CAD, each half is a sphere
cap truncated at the pod opening, and the LiDAR pod touches the ground at ~45-48° of
roll. The sim now carries the pods' collision geometry (stacked cylinders following
the CAD radial profile; strike at 44.5°), and a pod strike ends the episode.

**Mechanism 4: the task paid the policy to fight physics.** The reward demanded exact
tracking of any operator command, including speed/turn combinations outside the
coupled envelope. Tracking them anyway is precisely what produces mechanism 1.

**Two false leads, kept for the record.**
* "Lateral capability collapses above 4 m/s" was an artefact: fast straight-line
  test runs left the 60 m terrain patch and hit the geofence. Without it, Mk2.1 turns
  at > 4 m/s² at 6 m/s with ~0° roll. Steady turning is not roll-limited; transient
  braking-while-turning is (mechanism 1).
* A roll reaction wheel looked attractive (RT-G uses one). Measured, it adds ~1 point
  over the geometric fix and introduces gyroscopic roll-yaw-pitch coupling, so it was
  not adopted.

### Fixes, each at the layer of its cause
| layer | fix | evidence |
|---|---|---|
| hardware | **Mk2.1**: twin-crown offset 50 → 90 mm (width 700 → 780 mm), bob lean actuator 60 → 180°/s (back-drivable ball-screw in place of the worm), PI spine levelling | classical controller, same scenarios: falls 26.2 % → **10.9 %**, spine tilt 1.00° → **0.28°** (`rl/hw_study.py`) |
| simulation | pod collision geometry from CAD; failure = pod strike or pendulum loop | strike at 44.5° (CAD vertex analysis: 45-48°) |
| task | reward tracks a **feasible reference**: operator command shaped by the true slope (uniform + local terrain), friction, payload, motor strength and the stability ellipse. The policy still sees the raw command | — |
| curriculum | **ADR**: nine factors (terrain, slope, friction, pushes, wind, payload, actuator faults, sensor faults, speed), each with its own range, widened at ≥ 80 % and narrowed below 50 % success on pooled boundary tests | — |
| optimisation | entropy bonus removed, policy std capped at 0.35 (the bob action's std had drifted to its 0.5 cap) | — |

Hardware study (classical controller, fall %, 16 episodes per cell):

| scenario | Mk2 | lean 180°/s | crown 90 mm | wheel 8 N·m | wheel 15 N·m | **Mk2.1** | Mk2.1 + wheel |
|---|---|---|---|---|---|---|---|
| hills | 25 | 0 | 0 | 0 | 0 | **0** | 0 |
| rough + potholes | 19 | 12 | 12 | 6 | 6 | **6** | 0 |
| ramps to 15° | 19 | 12 | 6 | 12 | 6 | **0** | 6 |
| 12° incline | 88 | 81 | 56 | 88 | 88 | **56** | 56 |
| pushes to 350 N | 69 | 50 | 31 | 56 | 50 | **12** | 6 |
| wind 40 N + gusts | 44 | 38 | 19 | 31 | 31 | **12** | 12 |
| payload 10 kg off-centre | 38 | 44 | 12 | 31 | 25 | **12** | 6 |
| flat, 8 m/s | 38 | 56 | 44 | 50 | 38 | **50** | 50 |
| everything at once | 38 | 38 | 6 | 12 | 6 | **6** | 0 |
| **mean, all 16** | 26.2 | 23.4 | 12.9 | 20.7 | 17.6 | **10.9** | 9.8 |

The remaining classical failures (12° incline, 8 m/s) are braking/climbing-while-
turning beyond the stability ellipse: the classical controller tracks the raw command.
That is the job of the feasible-reference policy below.

## 3. Navigation v2
(pending)

## 4. Robustness matrices
(pending)

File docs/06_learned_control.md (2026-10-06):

# GYRA Mk2: learned control (asymmetric PPO)

Two policies, trained in MuJoCo on the CAD-derived Mk2 model:

1. **Locomotion / teleoperation policy** (50 Hz): turns joystick commands (v, ω) into
   motor torques and a bob setpoint.
2. **Autonomous navigation policy** (10 Hz): turns pod LiDAR, stereo depth and
   odometry into (v, ω) commands for policy 1.

Both use the **asymmetric actor-critic** setup (Pinto et al., 2017). The actor only
gets signals the real robot measures, with noise and latency. The critic additionally
gets privileged simulator state. Only the actor is deployed.

Code: `rl/loco_env.py`, `rl/nav_env.py`, `rl/ppo.py`, `rl/vec_env.py`,
`rl/train_loco.py`, `rl/train_nav.py`, `rl/eval_loco.py`, `rl/eval_nav.py`.
Everything runs on CPU: 4 cores, ~2 k env-steps/s for locomotion, ~250 nav-steps/s
per core.

## 1. Locomotion policy

### Structure: residual RL over an estimator-fed classical loop
A first, fully end-to-end run plateaued: speed error ~0.6 m/s, falls ~35 % of
episodes, and exploration noise growing (log in `rl/runs/archive/loco_e2e/`). With
CPU-only compute, the faster route is **residual RL**. The classical cascade controller
(speed → pendulum angle → torque, yaw-rate → differential torque, lateral
acceleration → counter-lean) runs on *estimated* state (IMU + encoders + noise), and
the policy adds a bounded correction: ±25 N·m on the drive sum, ±25 N·m on the
differential, ±0.35 rad on the bob. The whole stack stays deployable, and learning
starts from a working controller.

### Observations
| | actor (deployable) | critic (privileged) |
|---|---|---|
| IMU | gyro (3), gravity direction (3) | true body velocity (3), yaw rate, roll, pitch |
| encoders | pendulum angle (sin, cos) + rate, both drive-motor rates, bob angle | pendulum absolute angle + rate, bob |
| controller | previous action (3), classical base action (3) | contacts L/R |
| command | v, ω | v, ω, tracking errors |
| world | — | friction (μ, torsional, rolling), mass scales (4), CoM offset (3), motor strength, gravity tilt (2), push active |
| history | 4 frames (18 each) → 74 inputs | current frame → 48 inputs |

Noise: gyro 0.02 rad/s, gravity 0.015, encoder rates 0.05 rad/s, plus 0-1 control
steps of action latency.

### Domain randomisation (per episode)
Friction 0.5-1.2 · torsional 0.008-0.025 m · rolling 0.002-0.008 m · body masses
±10 % · spine CoM ±5 mm · motor strength 0.8-1.1 · slopes up to 12° in a random
direction (curriculum) · random 50-250 N shoves (curriculum) · commands resampled
every 2-5 s (turn in place, straight, stop, mixed with |v·ω| ≤ 4 m/s²).

### Reward (per 20 ms step)
exp(−e_v²/0.5) + exp(−e_ω²/0.5) − 0.15|e_v| − 0.15|e_ω| − 0.05 ω_roll² −
0.5 max(|roll| − 0.35, 0)² − 2 θ_spine² − 0.05 Δa² − 0.02 a² − energy − pendulum
slosh; −10 on a fall (pendulum over the top, or roll > 63°).

### Curriculum
Commanded speed range 4 → 8.5 m/s, and difficulty (slope range, push rate/magnitude)
0.5 → 1.0. It advances when the smoothed tracking errors and fall rate pass the
thresholds.

## 2. Navigation policy

| | actor (deployable) | critic (privileged) |
|---|---|---|
| LiDAR | 72-beam 2-D scan × 2 frames, synthesised from both pod Mid-360s, **with the forward/rear blind wedge** (returns hidden by the tyre are dropped), 2 cm noise, 2 % dropouts | true unmasked noiseless 72-beam scan, nearest-obstacle distance |
| vision | 16 × 8 front stereo depth image (90° × 45°), noise ∝ range², < 0.35 m invalid | — |
| odometry | goal distance/bearing from encoder + gyro dead reckoning (gyro bias, wheel-radius error → drift) | true goal vector, odometry error |
| state | speed estimate, yaw rate, previous action, time | true v, ω |

Action: (v_cmd ∈ [−1, 3.5] m/s, ω_cmd ∈ ±2.5 rad/s) to the frozen locomotion policy.
Reward: 3 × progress − 0.01/step − proximity penalty − action-rate penalty, +10 on
reaching the goal (< 0.6 m), −10 on collision or fall. Worlds: a 14 × 14 m walled
arena with 8-22 random cylinders and boxes (0.25-0.9 m tall), start/goal 4-10 m apart.

Baseline: a classical **VFH-style gap follower** using the same masked scan and the
same drifting odometry, driving through the same low-level policy.

## 3. Results

### 3.1 Locomotion (deterministic tests, `rl/runs/loco/eval.json`)
Deployed policy: the residual PPO checkpoint at 3.9 M steps (`rl/runs/loco/best.pt`,
TorchScript `actor.pt` + `actor_obs_norm.json`).

| test | classical alone | **classical + learned residual** |
|---|---|---|
| **6 m/s turn, 0.6 rad/s command** | **falls** (roll 69°), RMS yaw error 1.28 rad/s | **stable**, roll 7°, RMS yaw error 0.32 rad/s, radius 18.9 m |
| 4 m/s slalom (±0.8 rad/s) | yaw error 0.85 rad/s, roll oscillation to 6° | yaw error 0.53 rad/s, roll ≤ 1.5° |
| **random commands + randomised dynamics + shoves** (12 × 21 s) | **67% falls**, abs errors 1.73 m/s / 0.83 rad/s | **8% falls**, 1.35 m/s / 0.47 rad/s |
| 300 N shove at 3 m/s, peak roll | 13.6° | 10.8° |
| turn in place, 3 rad/s command | 171°/s | 176°/s |
| speed steps 0 → 8 m/s | RMS speed error 0.77 (acceleration-limited) | 0.75 |

locomotion evaluation

**Remaining flaw:** the learned residual has a small yaw-rate bias, about 0.2 rad/s at
low speed when commanded straight. RMS yaw error on the straight speed-step test is
0.16 vs 0.03 for the
classical loop. A heading-hold term or a symmetry-augmented training batch (mirror
left/right) is the next fix.

**What didn't work (kept for the record).**
1. *End-to-end PPO* (`rl/runs/archive/loco_e2e`) plateaued at ~0.6 m/s speed error
   with ~35 % falls, and its exploration noise kept growing.
2. *Training on to 8.5 M steps* with the hardest curriculum stage (7 m/s, 10.5° slopes,
   225 N shoves) **degraded** the policy: 42 % falls on the evaluation suite, against
   8 % at 3.9 M (`rl/runs/archive/loco_residual_to_8p5M/eval_8p5M.json`). The
   deployed checkpoint was chosen by evaluation, not by training reward.

### 3.2 Autonomous navigation (100 fixed random maps, `rl/runs/nav/eval.json`)
Both navigators drive through the same deployed locomotion policy and see the same
masked LiDAR and drifting odometry.

| | VFH-style baseline | **learned (asymmetric PPO)** |
|---|---|---|
| success | 72% | **79%** |
| collisions | 11% | **2%** |
| falls | 2% | 6% |
| time to goal (successes) | 9.6 s | **6.5 s** |
| mean speed (successes) | 0.86 m/s | **1.35 m/s** |

The learned navigator has **5.5× fewer collisions** and reaches goals **1.6× faster**.
It falls more often (6%): it asks the low-level for more aggressive
manoeuvres, and some of them exceed what the locomotion policy can hold. Next step:
fine-tune the two levels jointly, or add the low-level's roll margin to the navigator's
observation.

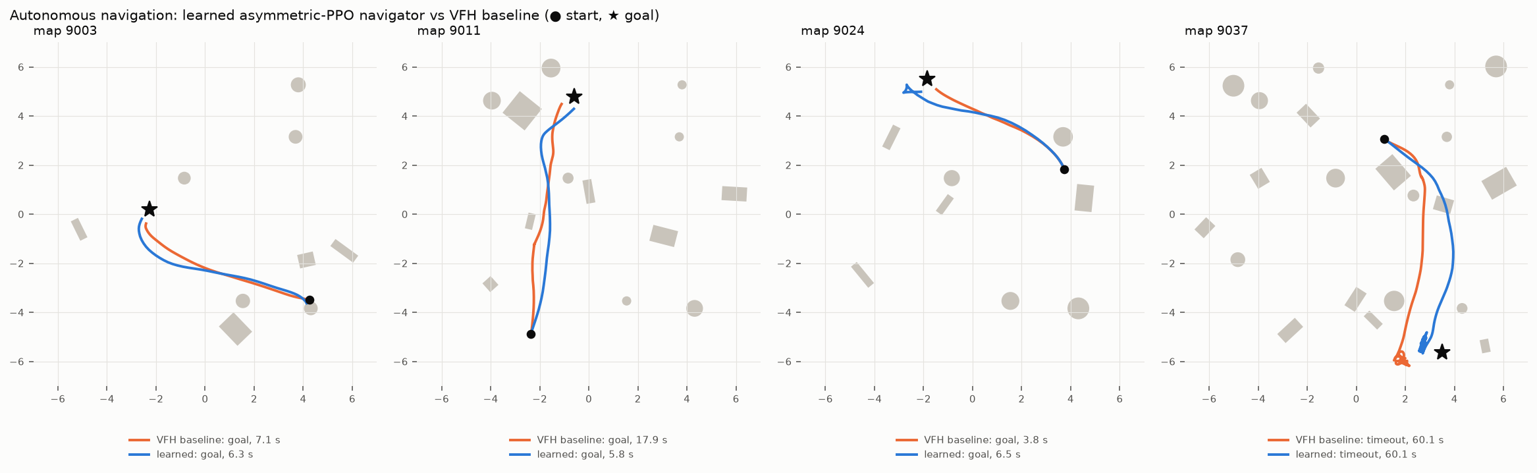
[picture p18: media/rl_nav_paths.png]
navigation paths


Example maps from the evaluation set (`rl/plot_nav.py`). On map 9037 **both**
navigators circle about 1.5 m short of the true goal. Their wheel/gyro odometry has
drifted, so they "arrive" in the odometry frame. On hardware this failure mode
disappears once the odometry is fused with the dual-antenna RTK GNSS and LiDAR SLAM.
In simulation it is the right stress test for a policy that sees only drifting odometry.

## 4. Deploying on hardware
* Run `actor.pt` (TorchScript) at 50 Hz on the Jetson. Observation = 4-frame history
  of gyro, gravity vector, pendulum/bob/drive encoders, previous action and the
  classical base action, plus the command, normalised with `actor_obs_norm.json`.
* The classical cascade runs alongside on the same estimates. The residual is added
  with the same ±25 N·m / ±25 N·m / ±0.35 rad clipping as in training.
* The levelling motor keeps its own PD loop.
* The navigator runs at 10 Hz on the Mid-360 scans (flattened to the 72-beam 2-D scan),
  the stereo depth from the two front cameras, and the wheel/gyro odometry.

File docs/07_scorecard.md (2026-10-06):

# Scorecard: RT-G vs GYRA Mk1 vs GYRA Mk2

Generated by `calc/scorecard.py` from the result files. RT-G values are published figures or
estimates from its paper's mass table using the same formulas as GYRA. All GYRA values are simulated.

| metric | RT-G / RotunBot | GYRA Mk1 | GYRA Mk2 (classical) | GYRA Mk2 (+ learned) |
|---|---|---|---|---|
| Diameter × width | 800 × 800 mm | 600 × 600 mm | 600 × 700 mm | 600 × 700 mm |
| Mass | 125-160 kg | 41.4 kg | 45.1 kg | same |
| Turn in place (mean yaw rate) | not possible (turns only while rolling) | 9°/s (CMG ratchet) | 163°/s @3 rad/s cmd · 258°/s @6 | 176°/s @3 rad/s cmd |
| Turn radius at 6 m/s | ~27 m (lean-precession estimate) | ~48 m (estimate) | 17.9 m (0.4 rad/s cmd; falls at 0.6) | 18.9 m at 0.6 rad/s cmd, no fall |
| Sensor-pod pitch, 0→3 m/s→0 | ≈ pendulum pitch (~40-46°) | 0.75° | 0.39° | same loop |
| Max grade (sim) | ~18° static est., 10° tested | 10° | 14° | 14° |
| Top stable speed | 10 m/s (paper) | 6.4 m/s (motor) | 8.5 m/s | — |
| Battery | ≈ 2.4 kWh (13S 50 Ah) | 468 Wh | 936 Wh | 936 Wh |
| Lateral shove 300 N @ 3 m/s, peak roll | — | — | 13.6° | 10.8° |
| Random commands, randomised dynamics + pushes: fall rate | — | — | 67% | 8% |
| … mean abs speed error | — | — | 1.73 m/s | 1.35 m/s |
| … mean abs yaw-rate error | — | — | 0.83 rad/s | 0.47 rad/s |
| 6 m/s turn (0.6 rad/s cmd): RMS yaw-rate err / max roll / fell | — | — | 1.28 / 69° / True | 0.32 / 7° / False |
| 4 m/s slalom (±0.8 rad/s): RMS yaw-rate err / max roll / fell | — | — | 0.85 / 6° / False | 0.53 / 1° / False |
| speed steps to 8 m/s: RMS yaw-rate err / max roll / fell | — | — | 0.03 / 0° / False | 0.16 / 0° / False |
| Autonomous nav, 100 random maps: success | L4 autonomy claimed (no data) | — | 72% (VFH baseline) | 79% (learned) |
| … collision rate | — | — | 11% | 2% |
| … mean speed on successful runs | — | — | 0.86 m/s | 1.35 m/s |

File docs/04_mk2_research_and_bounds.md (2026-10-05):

# Toward GYRA Mk2: what can get 10× better, and what physics won't allow

The goal for Mk2 is "orders of magnitude better at every aspect". This document
separates the metrics where 10× or more is physically reachable from those where a
hard physical ceiling exists, so the design effort goes where it pays.

## 1. The ceilings every internal-drive sphere hits

A closed sphere gets **no traction force except through its own shell**. Every
propulsive torque comes from an internal mass the shell pushes against. With M the
total mass, m_p and L the pendulum mass and lever arm, R the radius and θ the pendulum
swing:

| quantity | bound | Mk1 value | best realistic |
|---|---|---|---|
| grade | sin α ≤ (m_p / M)(L / R) sin θ | 13.6° (10° rated) | m_p/M → 0.6, L/R → 0.72 ⇒ **~26°** |
| acceleration | a ≤ g (m_p L)/(M_eff R) | 1.9 m/s² | ~4 m/s² |
| top speed | motor and stability, not traction | 6.4 m/s | 10-12 m/s (RotunBot ran 10 m/s) |
| static step | h = R(1 − cos α) | 8 mm | ~30 mm (kinetic: ~0.4 R) |

**Grade and acceleration cannot improve 10×.** Even an all-pendulum robot with
L = R reaches only sin α = 1. The realistic gain is about 2×, from moving everything
heavy into the pendulum (battery, compute, electronics) and pushing the pendulum's
centre of mass outward.

## 2. Where 10× *is* available

| metric | why Mk1 is weak | Mk2 lever | expected gain |
|---|---|---|---|
| **yaw rate at standstill** | CMG yaw mode is impulse-limited (2h per sweep), ~9°/s average | **split tyre, differential drive**: continuous yaw torque 2·F·d, limited only by pivot friction | **> 10×** (target > 120°/s) |
| **turn radius at speed** | lean precession: ρ = J v²/(τ R), so 48 m at 6 m/s | differential yaw torque + bob counter-lean; ρ limited by tip-over v²/(g·e/h) | **~5-8×** |
| **roll wobble** | single contact point, gyroscopic coupling | **twin-crown tyre**: two contact patches 120 mm apart give passive roll stiffness M·g·d | wobble mode suppressed without CMGs |
| **mass spent on stabilisation** | 5.9 kg of CMGs + 1 kg gimbal motors | removed: the twin crown handles roll and the differential handles yaw | −7 kg, all of it turned into battery ballast |
| **endurance** | 468 Wh | the battery *is* the ballast, so a 3× bigger pack costs no extra mass | **~3×** (≈ 13 h at 3 m/s) |
| **autonomy** | hand-tuned PD/PI loops, no navigation | learned locomotion + navigation policies (asymmetric PPO) | new capability |
| **sensor stability** | already 0.75° vs ~46° for an RT-G-style pod | keep the levelled spine | ≈ 60× vs RT-G (kept) |

## 3. The split-tyre idea in detail

Prior art. Split-hemisphere differential steering is an established family of
spherical robots: a Chinese patent on a *hemispherical differential retractable
spherical robot* (CN103387016B), and research robots with "two individually driven
semi-spheres". A 2026 *Actuators* paper (MDPI 15/4/181) decouples rolling (pendulum)
from turning with a gear-rack yaw mechanism. **What none of these combine** is a
split tyre with a **non-rotating, levelled sensor axle**, a **twin-crown rubber
profile** for passive roll stiffness, and **one pendulum reacting both drives**.

How it works:
* Each tyre half is a spherical zone whose crown is offset outward by **d = 60 mm**:
  its surface is a sphere of radius R centred at (0, ±d, 0). Upright, the robot
  stands on **two patches 120 mm apart**. The centre seam sits 6 mm below the crowns,
  so it never touches flat ground.
* Each half has its own internal ring gear and its own drive motor. Both motors react
  on the same pendulum: the **sum** of their torques swings the pendulum (forward
  drive), and the **difference** cancels inside the pendulum and appears only as a
  **yaw couple at the ground**: τ_yaw = (F_L − F_R)·d.
* Turn in place: counter-rotate the halves. Each patch rolls on a circle of radius d,
  so the only resistance is pivot friction (~8.5 N·m). Each motor needs about 28 N·m
  at the tyre for that, well inside the 6374 + 30:1 drive's 100 N·m peak, and
  **independent of the pendulum limit** because the difference torque never reaches
  the pendulum.
* High-speed turns: the turn is commanded directly by the differential, and the bob
  leans the CoM inward to stop tip-over. Lateral acceleration is limited by
  a_tip ≈ g·(d + e_bob)/h_CoM.

## 4. Learning-based control: the plan

* **Asymmetric actor-critic** (Pinto et al., 2017): the actor sees only what the real
  robot measures (IMU, motor encoders, pendulum/bob encoders, LiDAR, depth). The critic
  additionally gets privileged simulator state (true velocity, friction, masses, slope,
  obstacle map). Only the actor is deployed.
* **Locomotion / teleoperation policy**: tracks (v, ω) joystick commands at 50 Hz,
  outputting the two drive torques and the bob setpoint. It is trained with domain
  randomisation (mass, CoM offset, friction, motor strength, latency, sensor noise,
  slopes, pushes).
* **Autonomous navigation policy**: at 10 Hz it outputs (v, ω) commands to the frozen
  locomotion policy. Inputs are a 2-D scan synthesised from the two pod LiDARs, **with
  the real forward blind wedge modelled**; a low-resolution depth image from the front
  stereo pair; encoder/IMU odometry; and the goal in the odometry frame. Its critic
  sees the true pose and a local occupancy grid.
* Prior art for this structure: RL spherical-pendulum tracking with zero-shot sim-to-real
  (arXiv:2309.14096), LiDAR-ray PPO navigation on differential-drive robots, and the
  Zhejiang group's MPC trajectory tracking on the RotunBot platform (arXiv:2303.18186,
  2205.14181). RL locomotion for a **pendulum-driven sphere** appears to be unpublished.

## Sources
* Split-hemisphere patent CN103387016B: https://eureka.patsnap.com/patent-CN103387016B
* *Mechanically Decoupled Rolling and Turning Design for Pendulum-Driven Unmanned Spherical Robots*, Actuators 15(4):181: https://www.mdpi.com/2076-0825/15/4/181
* GuardBot (pendulum drive, 22 in, 25 h endurance): https://physicstoday.aip.org/news/meet-guardbot
* Pinto et al., *Asymmetric Actor Critic for Image-Based Robot Learning*: https://www.semanticscholar.org/paper/Asymmetric-Actor-Critic-for-Image-Based-Robot-Pinto-Andrychowicz/ae096b868323f74a68414ae8855e20669540e2ba
* *Tracking Control for a Spherical Pendulum via Curriculum RL*: https://arxiv.org/abs/2309.14096
* *Adaptive MPC multi-terrain trajectory tracking for mobile spherical robots*: https://arxiv.org/abs/2303.18186
* *Direction and trajectory tracking control for nonholonomic spherical robot (SMC + MPC)*: https://arxiv.org/abs/2205.14181
* *Deep RL with enhanced PPO for safe mobile robot navigation*: https://arxiv.org/abs/2405.16266

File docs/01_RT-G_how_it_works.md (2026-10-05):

# How the RT-G actually works

This is a reverse-engineering report on the **RT-G** spherical patrol robot. It is built from
the only primary technical source available, the 2025 Zhejiang University paper on the
same machine, cross-checked against press coverage and the company's own statements.

---

## 1. Who makes it

| | |
|---|---|
| Product | **RT-G** "spherical amphibious patrol robot" (police variant shown in Wenzhou, Dec 2024) |
| Company | **Logon / Luoteng Technology** (逻腾科技, also styled *Rotunbot*), Qiantang district, Hangzhou |
| Founder | **Wang You** (王酉), associate professor, Institute of Cyber-Systems & Control, Zhejiang University |
| Research name | **RotunBot**. Paper: B. Zhang, F. Zhang, H. Chen, **Y. Wang**, J. Hao (*Luoteng Hangzhou Technology*), Z. Luo, G. Li, *"A High-Speed Capable Spherical Robot"*, arXiv:2511.01288 |
| History | Development started in 2017 (planetary-exploration inspiration). Mass production started in 2023 after a second funding round. Other sizes include 60 cm and 80 cm variants. |

Published numbers don't all agree. Press articles say **125 kg**. The paper and the Hangzhou
government article say **≈160 kg**. The other figures: shell radius **40 cm** (Ø 80 cm),
**35 km/h** claimed (10 m/s measured in the paper), 0→30 km/h in 2.5 s, "withstands 4 t
impacts", **10 h** endurance (≈120 km), −45…85 °C, amphibious.

## 2. The internal architecture (from the paper's CAD figure and Table I)

```
                 external component (sensor pod)          external component (sensor pod)
                 rigidly bolted to the MAIN SHAFT          rigidly bolted to the MAIN SHAFT
                        │                                            │
   ┌────────────────────┴────────────────────────────────────────────┴────────────┐
   │  ═══════════════════════  aluminium MAIN SHAFT (spans the sphere)  ════════  │
   │      │ (1) main drive: motor on the frame → gear → FLANGE bolted to SHELL    │
   │      │ (3) momentum-wheel motor → belt → MOMENTUM WHEEL Ø420 mm, 9.8 kg      │
   │      │     (wheel axis = direction of travel → it produces ROLL torque)       │
   │      │ (2) auxiliary drive: lifts the HEAVY PENDULUM sideways (about x)       │
   │      ▼                                                                       │
   │   HEAVY PENDULUM 73.4 kg (cast steel + lead, the battery is inside it)        │
   └──────────────────────────────────────────────────────────────────────────────┘
          SHELL 27.6 kg: polyester-fibre-reinforced RUBBER with an off-road tread
```

Mass breakdown (paper, Table I). Total ≈ 160 kg, shell radius 40 cm, pendulum arm ≈ 27 cm:

| component | material | kg |
|---|---|---|
| heavy pendulum (incl. battery) | cast steel + lead blocks | 73.4 |
| spherical shell (incl. flange plate) | polyester-fibre-coated rubber | 27.6 |
| momentum wheel | cast steel | 9.8 |
| external components (both sides) | nylon shield + sensors | 15.1 |
| main shaft + everything else | aluminium alloy | 34.3 |

Electronics: 13S, 50 Ah Li-ion pack (≈2.4 kWh). An STM32F407 talks to three servo drives
over CAN at 100 Hz. An onboard computer runs navigation and SLAM over UDP. Industry
coverage adds stereo cameras with a baseline over 50 cm, mounted in the side shells
(the "insect compound eye" camera ring), plus GNSS, an IMU and motor encoders. Larger
models use an Intel i7 with an RTX 2060.

### How it drives
The **main motor sits on the internal frame** and drives a gear meshed with a **flange
that is bolted to the shell**. The motor's reaction torque has nowhere to go except into
the frame. The frame rotates forward around the shaft and lifts the 73 kg pendulum off
vertical. The centre of mass moves ahead of the contact point and gravity rolls the ball.
**Drive torque is limited by gravity × pendulum offset, not by the motor**:

  τ_max = m_p · g · L_p · sin θ  ⇒  max grade ≈ asin(m_p L_p / (M R)) ≈ 18° for the RT-G.

### How it steers ("gyro steering")
The **auxiliary motor swings the pendulum sideways**, which moves the centre of mass
laterally and tips the shaft over. The shell is spinning, so it has angular momentum
**L** along the shaft. The sideways gravity torque τ, along the direction of travel,
makes **L** precess about the vertical: dL/dt = τ. The robot **yaws toward the side it
leans to**, like a rolling coin. The turn rate is Ω = τ / L, so the turn radius grows
with v². This is why the RT-G turns tightly at walking pace but needs very wide arcs at
35 km/h. The paper sums it up: *"RotunBot completes steering tasks by moving forward and
backward while in a tilted state."*

### What the "gyroscope" really does
The **momentum wheel** (axis along the direction of travel) is a **reaction wheel for the
roll axis**. Speeding it up or slowing it down puts a roll torque on the body without
moving the centre of mass. The paper splits the job between the two actuators:

* pendulum = **roll angle** setpoint (segmented PI + model feed-forward, eq. 3: θ_ref = θ_hope + sin⁻¹(m v² tan θ_hope / (m_p g r)))
* momentum wheel = **roll rate → 0** (segmented PD)

Without the wheel, the single-pendulum ball diverges in roll above about 2 m/s when
turning and decelerating. With it, the authors report 10 m/s straight-line runs with
less than 0.05 rad roll ripple. They also cleared a 17 cm step at speed, climbed 10°
slopes, and recovered from a 0.4 rad roll kick (hitting a 10 cm brick at 4 m/s) in
under 2 s.

## 3. Your hypothesis, checked

> *"the wheel turns with a motor while the axis stays stable, so you can put LiDAR and cameras on the sides, and use a rubber wheel instead of a transparent ball"*

**Mostly right.** The details:

1. ✅ **Only the central shell rotates.** The side pods bolt to the main shaft, so they
   never spin with the tyre. Sensors look out directly, with no transparent, scratched,
   dirty or refracting hull in the way. That is also why the shell can be an opaque,
   tough, **fibre-reinforced rubber tyre with a real tread**.
2. ⚠️ **"Stable" means gravity-stabilised, not gyro-stabilised.** The shaft and pods are
   held level only by the hanging pendulum, and they are rigid with the frame that
   pitches with it. When the RT-G accelerates, brakes or climbs, **the pods pitch with
   the pendulum** (tens of degrees in a hard launch). When it leans into a turn, they
   **roll**. The "compound-eye" software de-jitters the video using IMU attitude.
3. ✅ **It turns with gyroscopic physics**, but the gyroscope is the **spinning tyre
   itself**. The momentum wheel only damps roll wobble; it doesn't steer.
4. ⚠️ It is **non-holonomic, like a unicycle**. It can't roll sideways, and it turns
   only while rolling, or with fore-and-aft shuffling.

## 4. RT-G vs. "traditional" ball robots

| | Sphero / BB-8 / hamster-ball (internal drive unit) | Omni-wheel / ballbot-in-a-ball | Classic pendulum sphere (GroundBot, Rollo, BHQ) | **RT-G / RotunBot** |
|---|---|---|---|---|
| What rotates | whole shell, any direction | whole shell, any direction | whole shell (1-2 axes) | **central tyre band only (1 axis)** |
| Drive | small car or wheels pushing the shell inside | omni-wheels on the shell inside | pendulum CoM offset | **pendulum CoM offset (geared to flange)** |
| Sensors | inside, looking through the shell (or none) | inside | inside or in transparent side domes | **in opaque side pods on the axle, direct view** |
| Shell | transparent or smooth plastic | smooth | polycarbonate | **rubber tyre with tread, 27.6 kg** |
| Steering | differential drive inside | holonomic | lateral pendulum (wobbly) | **lateral pendulum + momentum-wheel roll damping** |
| Weakness | slips, low torque | slips, complex | wobble, slow | **heavy, grade-limited, pods still pitch** |

Its closest ancestor is **GroundBot** (Rotundus, Uppsala, 60 cm, glass camera domes on
the axle ends). RT-G's real contributions are scale, a **rubber traction tyre**, a
**high-speed controller** and the **momentum wheel that separates roll stabilisation
from steering**.

## 5. What I took from this for GYRA

* Keep: sensors on the non-rotating axle ends, a rubber tyre over most of the sphere,
  pendulum drive, lean-steering, sealed amphibious body.
* Fix: (a) the pods pitch with the pendulum, (b) a single reaction wheel saturates and
  only handles roll, (c) no turn-in-place, (d) the drive gear sits at small radius on a
  side flange, (e) the lateral pendulum must hold the lean against gravity with power.

See [`02_GYRA_Mk1_design.md`](02_GYRA_Mk1_design.md).

## Sources
* Zhang, Zhang, Chen, Wang, Hao, Luo, Li, *A High-Speed Capable Spherical Robot*, arXiv:2511.01288 (Zhejiang Univ. + Luoteng Hangzhou Technology): https://arxiv.org/abs/2511.01288
* Singhal, Modi, Gupta, Vachhani, *Wobble control of a pendulum actuated spherical robot*, arXiv:2301.06433: https://arxiv.org/abs/2301.06433
* Hangzhou government news, *Hangzhou's spherical robot grabs global attention*: https://www.ehangzhou.gov.cn/2025-02/21/c_292708.htm and https://www.ehangzhou.gov.cn/2025-02/27/c_292781.htm
* 机器人大讲堂, *"大黑球"火爆全网…浙大王酉团队全面起底*: https://leaderobot.com/news/4946
* 网易, *逻腾王酉：球形机器人布局千亿市场*: https://www.163.com/dy/article/IB5HUII10511C9QL.html
* New Atlas, *Chinese police trial amphibious crime-fighting robot sphere*: https://newatlas.com/robotics/chinese-police-amphibious-robot-ball/
* Interesting Engineering: https://interestingengineering.com/innovation/chinas-spherical-robot-cop-captures-criminals
* Yanko Design: https://www.yankodesign.com/2024/12/17/rolling-crime-fighting-machine-the-futuristic-robot-redesigning-law-enforcement/
* Robots Asia product page: https://www.robotsasia.com/Rotunbot-RT-G.htm
* Rotundus GroundBot: https://newatlas.com/rotundus-groundbot/20259/ and https://orionrobots.co.uk/wiki/rotundus.html

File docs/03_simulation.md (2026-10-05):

# GYRA Mk1: physics simulation (MuJoCo 3)

`sim/gyra_model.py` generates the MJCF straight from `cad/out/mass_properties.json`.
Every body uses its CAD mass, centre of mass and full inertia tensor, so the simulation
and the CAD can't drift apart. `sim/scenarios.py` runs the closed-loop experiments
below; the numbers come from `sim/out/summary.json`.

```
python cad/gyra_cad.py      # CAD → mass properties
python sim/scenarios.py     # ≈ 10 s on a laptop, writes media/sim_*.png
```

## Model
* Kinematic tree: spine (free) → {tyre ⟂y, yoke ⟂y → bob ⟂x, cmgL ⟂y → flyL ⟂z, cmgR ⟂y → flyR ⟂z}. 13 DoF.
* Contact: tyre = sphere R 0.30 m, `condim 6` (sliding μ = 1.0, torsional 0.021 m = ⅔·μ·a for a 35 mm patch, rolling 0.006 m ≈ C_rr 0.02).
* Drive torque acts between yoke and tyre through a fixed tendon (`tyre − yoke`), so the reaction lands on the pendulum, as on the real robot. The levelling motor acts between yoke and spine.
* Flywheels spin at ±10 000 rpm under velocity servos. Gimbals are velocity servos limited to ±12 N·m. The lean drive is a stiff position servo, rate-limited to 45°/s (worm).
* 0.5 ms implicit-fast integrator, 500 Hz control.

## Controllers (all deliberately simple)
| loop | law |
|---|---|
| speed | cascade: PI(v) → pendulum swing set-point, **clamped ±65°** (never drives the pendulum over the top) → PD → drive torque |
| spine levelling | PD on spine pitch → levelling motor |
| heading hold | lean (bob) ∝ heading error − yaw rate (precession steering) |
| CMG roll mode | scissor gimbal rate γ̇ = k·ω_roll / (2h cos γ) − c·γ (roll-rate damping + centring) |
| CMG yaw mode | gimbals parked at ±90°, fast common sweep −60° → +60°, slow return |

## Results

### 1. Drive: the levelled spine works
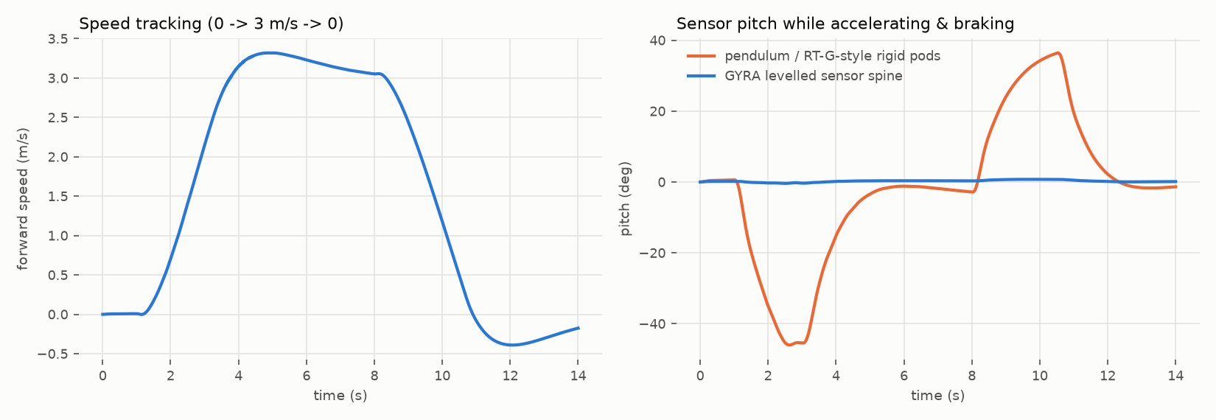
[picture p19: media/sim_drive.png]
drive


The robot runs 0 → 3 m/s → 0 (cruise 3.2 m/s). During the launch **the pendulum
(which is what an RT-G pod is bolted to) pitches 46°**. **The GYRA sensor spine peaks
at 0.75°.**

### 2. Lean-steer at 2 m/s: the CMG kills the wobble
turn

At t = 5 s the bob steps to 25° and holds:

| | roll std | roll peak-to-peak | turn radius |
|---|---|---|---|
| pendulum only (CMG off) | 24.5° | **89°**, growing | ill-defined (5.0 m mean) |
| **CMG roll damping on** | **0.48°** | **1.4°** | **5.8 m** |

Pendulum-only, the lean step excites the classic pendulum-sphere wobble mode, and at
2 m/s it grows. The RotunBot paper reports the same divergence above 2 m/s without its
momentum wheel. With the CMG pair damping roll rate, the robot settles into a clean
circle. The **simulated 5.8 m radius matches the closed-form precession estimate of
5.3 m** (`calc/sizing.py`) to within 10 %.

Note: the "off" case uses an open-loop lean step. The RT-G closes a PI loop on roll
angle with its pendulum, which helps at low speed but is limited by the pendulum's
slow, heavy dynamics. The CMG adds roll authority at a bandwidth the pendulum can't
reach.

### 3. Turn-in-place at zero speed
spin

The gimbals are first parked at ±90° (slowly, so the roll disturbance stays small).
Then each fast common sweep (−60° → +60° at 4 rad/s, about 15 N·m of yaw torque, well
above the 8.5 N·m pivot friction) spins the robot about 110°. The slow return gives
back about 35°, because the simulated rubber has finite stiction, even with MuJoCo's
no-slip solver. **Net 315° in four 6-second cycles, with 7 cm of drift.** The
closed-form estimate is ~73° net per sweep; the simulation gives ~79°.

### 4. Grades
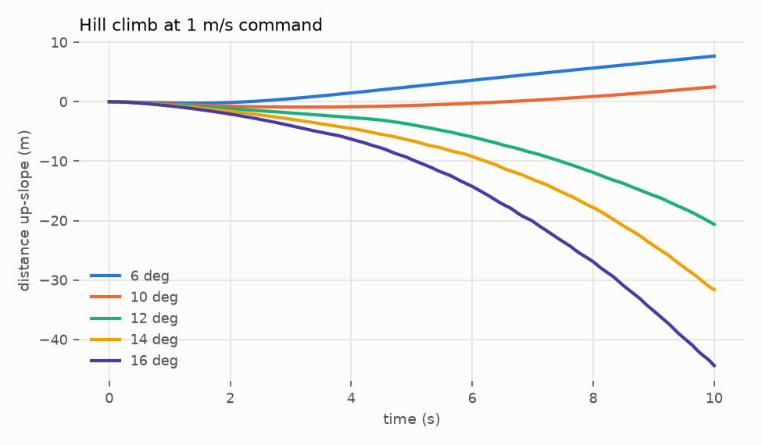
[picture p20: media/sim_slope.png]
slope


With the pendulum clamped at ±65°, the theoretical static limit is
asin(m·L·sin65°/(M·R)) ≈ 12.3°. In the simulation, GYRA climbs **6° (7.7 m in 10 s)**
and **10° (slowly)**, and slips back at 12°. **Rated grade: 10°.** This is the main
target for Mk2 (see the design doc).

## Limits of this model
* The tyre is a rigid sphere with point-contact friction. Real tread deformation, patch
  growth on soft ground, and the pods touching the ground during extreme leans aren't
  modelled.
* Motor electrical dynamics, belt compliance and gear backlash are ignored, and the
  levelling motor is ideal within ±12 N·m.
* Stiction in MuJoCo is approximate, so treat turn-in-place efficiency as an estimate
  until hardware tests.

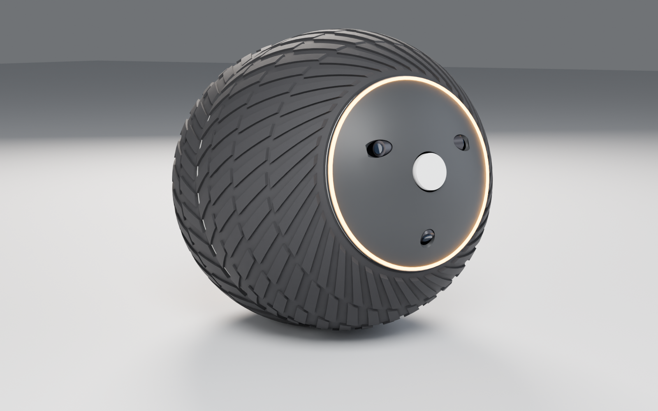
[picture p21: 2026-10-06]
media/mk2_leaning_turn.png

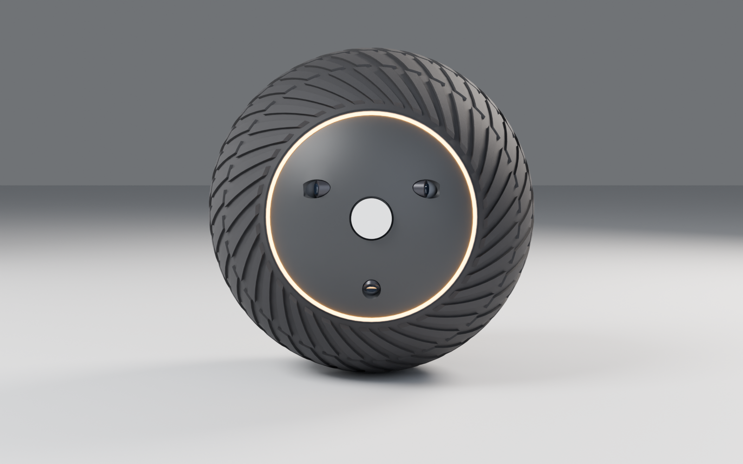
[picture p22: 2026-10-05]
media/gyra_side.png

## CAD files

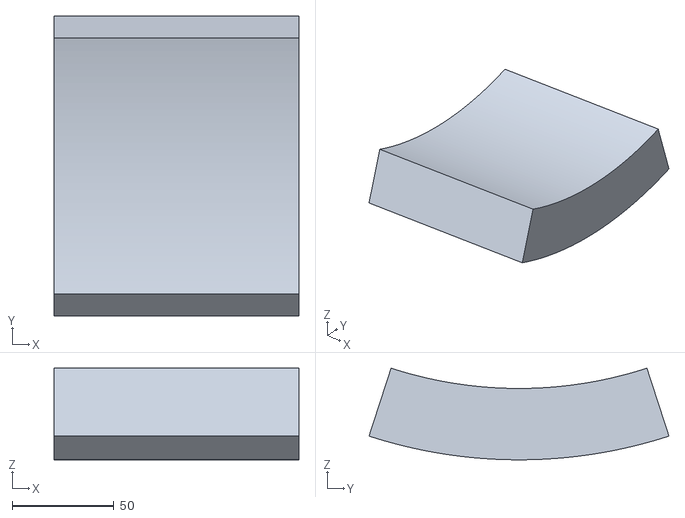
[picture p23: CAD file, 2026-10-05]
cad/out/stl/bob_lead.stl
120.0 x 147.1 x 44.9

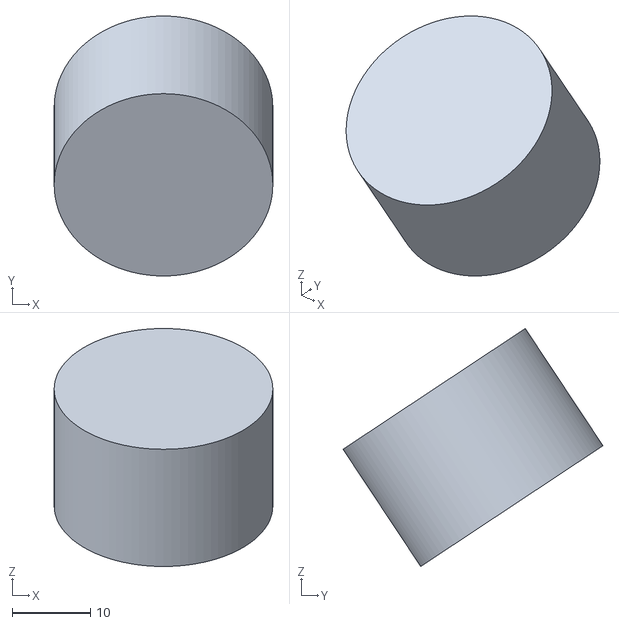
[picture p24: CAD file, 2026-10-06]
cad/out21/stl/cam2_L.stl
28.0 x 33.3 x 30.5

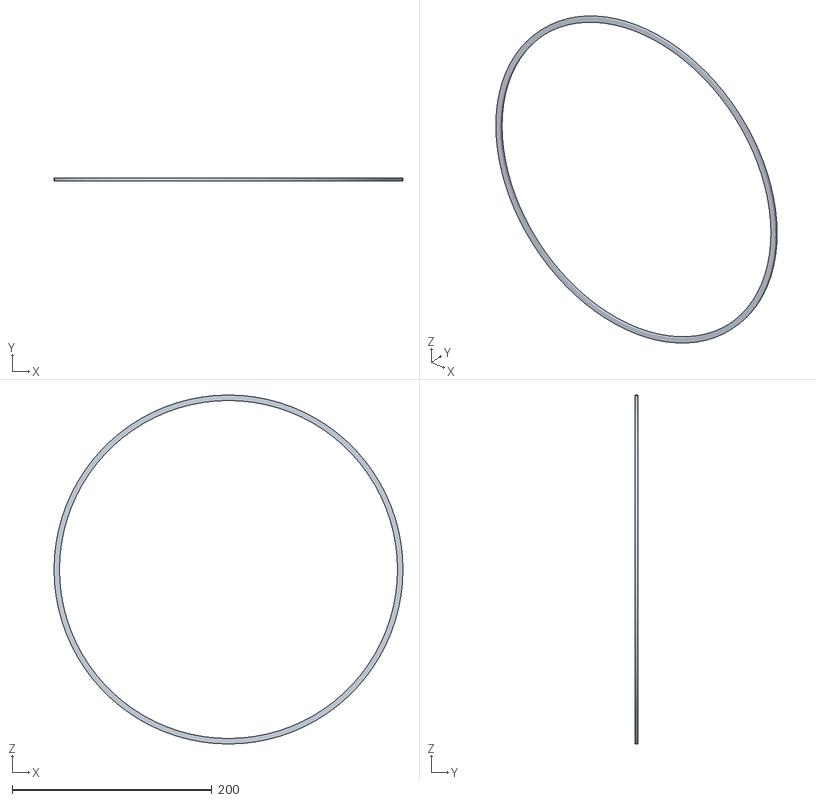
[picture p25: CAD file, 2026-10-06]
cad/out21/stl/led_ring_L.stl
349.0 x 3.00 x 349.0

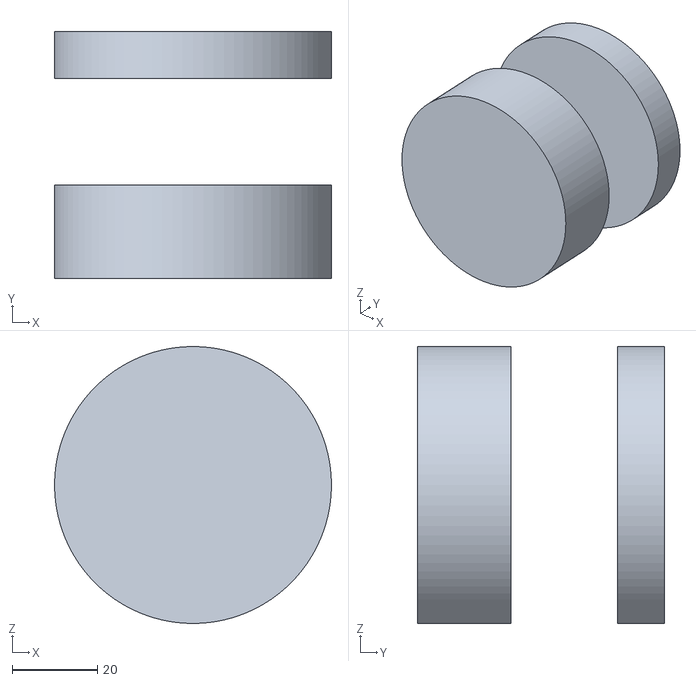
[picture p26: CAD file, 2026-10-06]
cad/out21/stl/lidar_body_L.stl
65.0 x 58.0 x 65.0

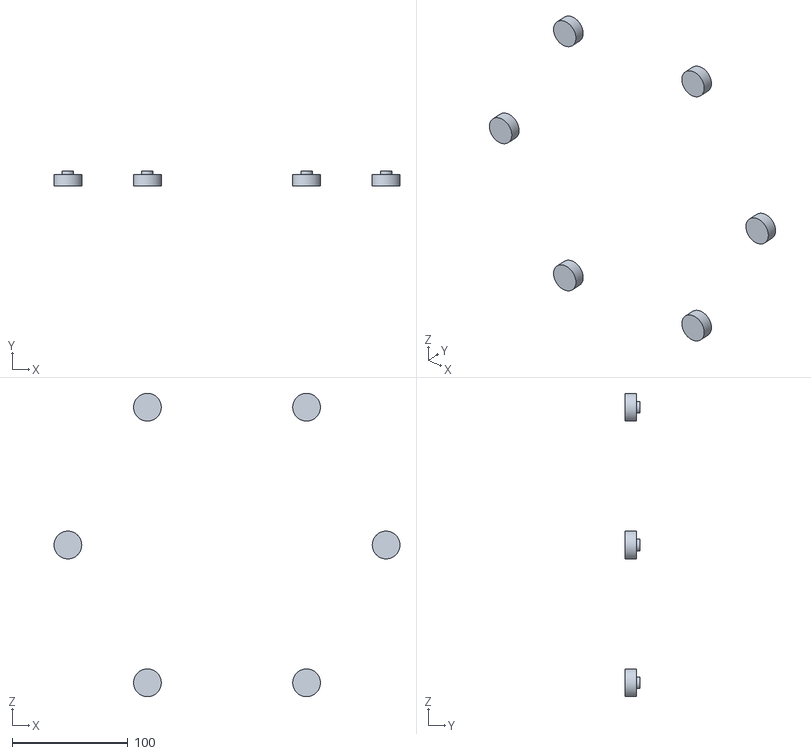
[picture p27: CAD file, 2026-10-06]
cad/out21/stl/rollers_L.stl
299.0 x 13.0 x 262.2

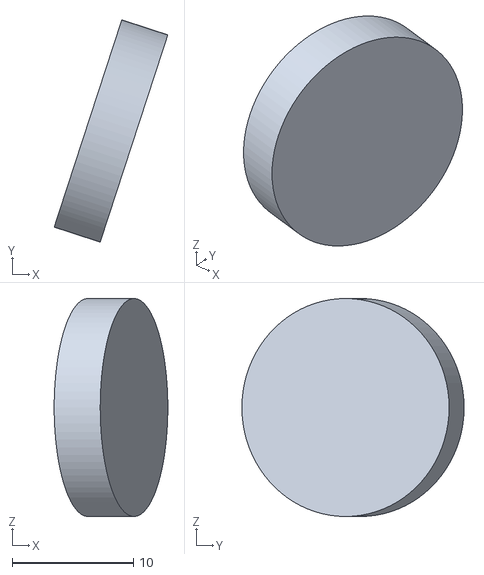
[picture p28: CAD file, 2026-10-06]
cad/out21/stl/lens0_R.stl
9.39 x 18.4 x 18.0

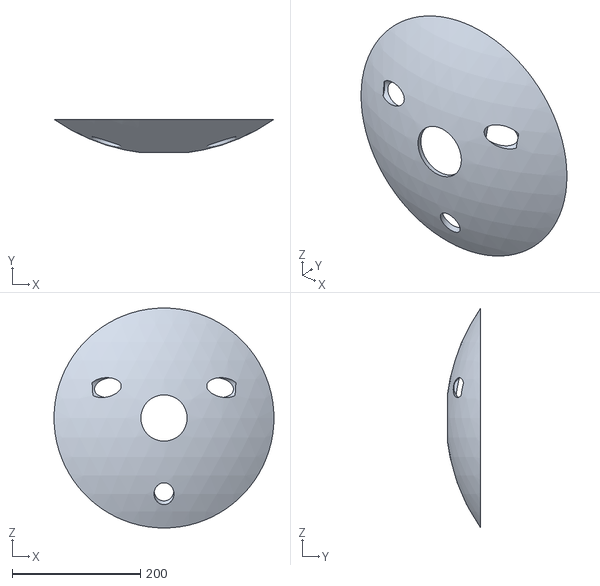
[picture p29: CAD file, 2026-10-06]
cad/out21/stl/pod_shield_R.stl
342.8 x 51.8 x 342.8

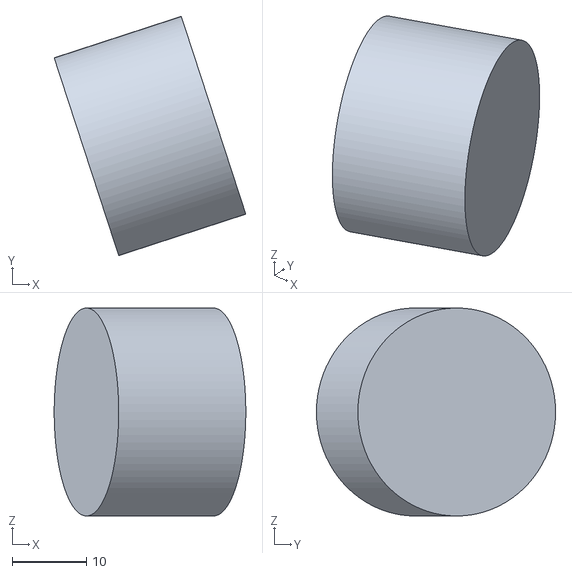
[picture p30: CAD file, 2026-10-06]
cad/out21/stl/cam0_L.stl
25.8 x 32.2 x 28.0

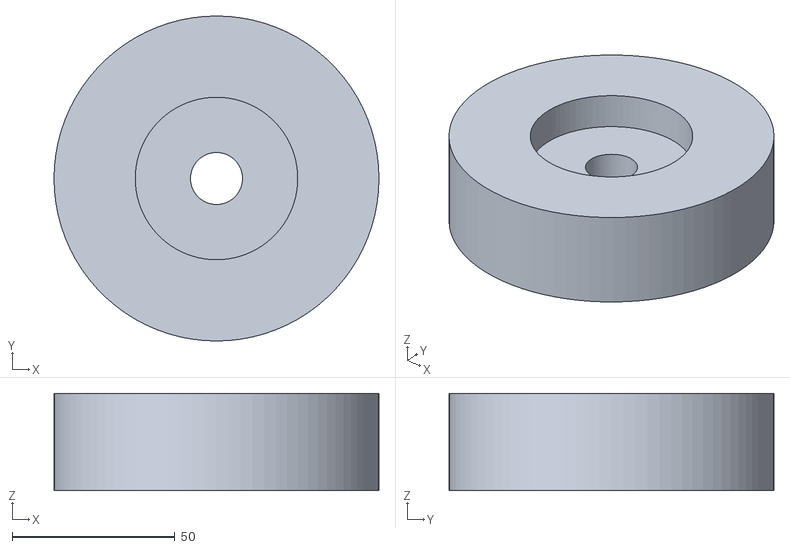
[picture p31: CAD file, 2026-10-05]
cad/out/stl/flywheel_R.stl
100.0 x 100.0 x 30.0

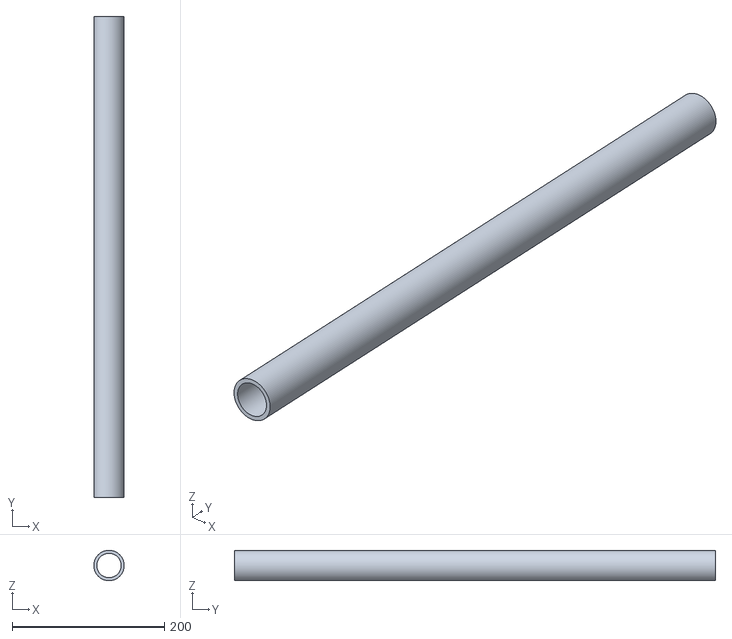
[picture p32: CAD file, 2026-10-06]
cad/out21/stl/axle.stl
40.0 x 632.0 x 40.0

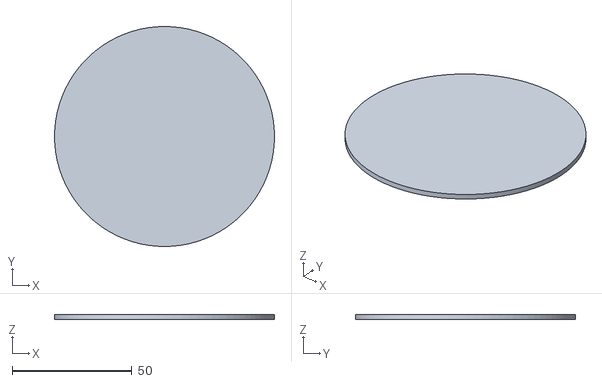
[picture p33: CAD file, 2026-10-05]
cad/out/stl/cmg_lid_L.stl
92.0 x 92.0 x 2.00

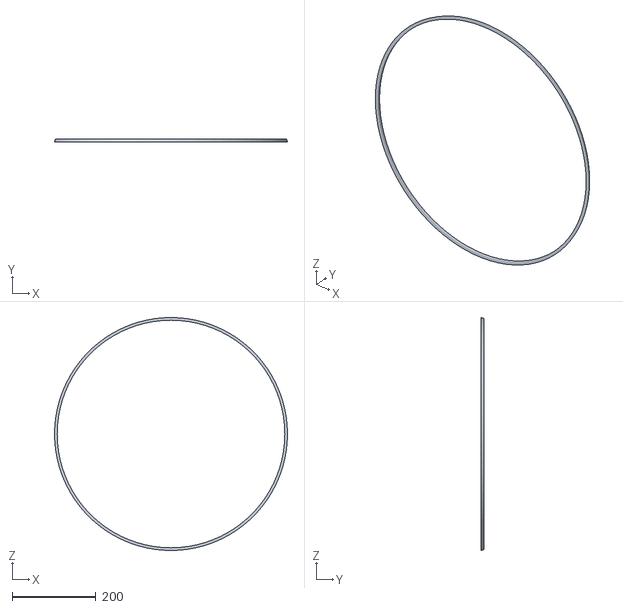
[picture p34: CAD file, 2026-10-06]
cad/out21/stl/eq_flange_R.stl
557.1 x 6.00 x 557.1

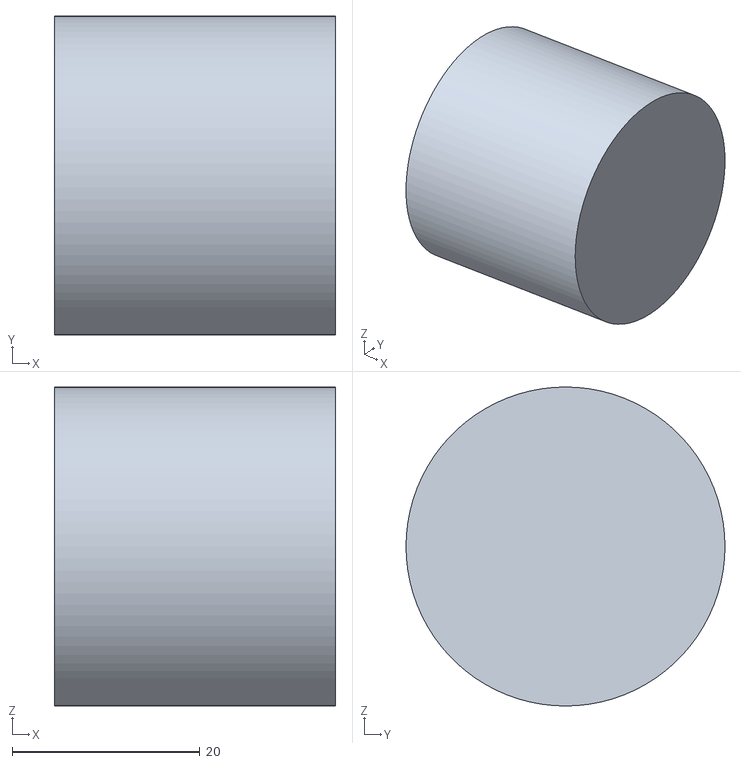
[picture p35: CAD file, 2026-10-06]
cad/out21/stl/bob_lean_drive.stl
30.0 x 34.0 x 34.0

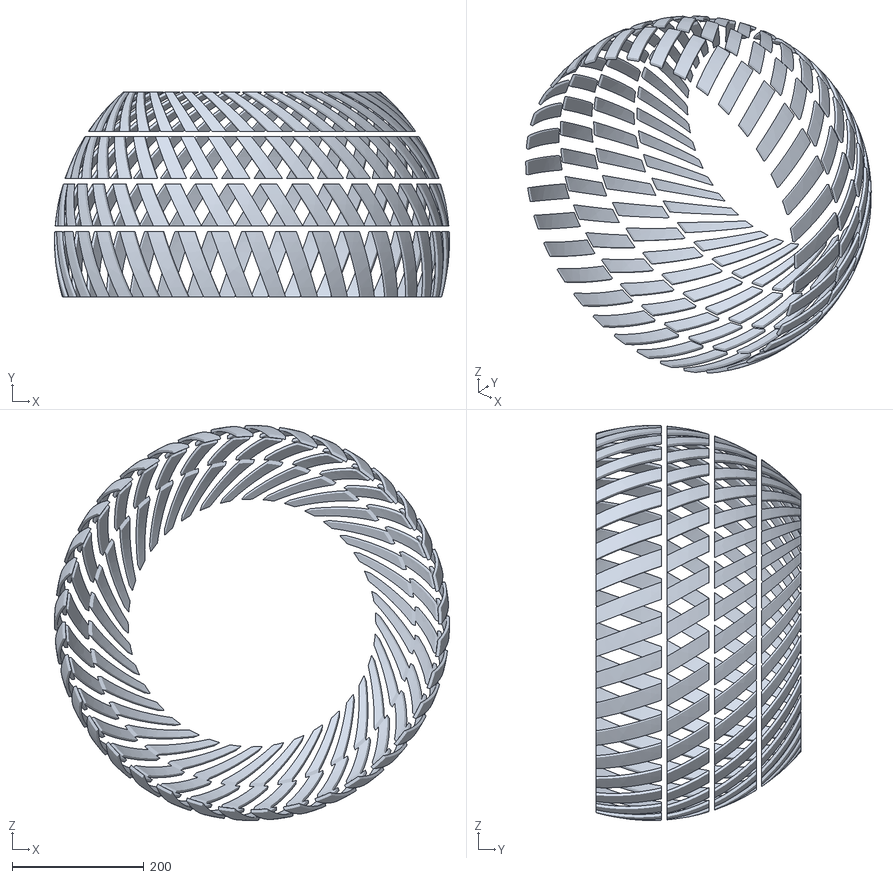
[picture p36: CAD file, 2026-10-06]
cad/out21/stl/lugs_L.stl
599.9 x 312.0 x 599.9

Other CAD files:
cad/out21/stl/lens2_R.stl
cad/out/stl/gimbal_bearing_R.stl
cad/out21/stl/led_ring_R.stl
cad/out21/stl/pod_shield_L.stl
cad/out/stl/arc_plate_B.stl
cad/out/stl/arc_plate_F.stl
cad/out/stl/axle.stl
cad/out/stl/axle_flange_L.stl
cad/out/stl/axle_flange_R.stl
cad/out/stl/bay_L.stl
cad/out/stl/bay_R.stl
cad/out/stl/bay_strut_L.stl
cad/out/stl/bay_strut_R.stl
cad/out/stl/belt_B.stl
cad/out/stl/belt_F.stl
cad/out/stl/bob_battery.stl
cad/out/stl/bob_carriage.stl
cad/out/stl/bob_rails.stl
cad/out/stl/bob_worm_motor.stl
cad/out/stl/cam0_L.stl
cad/out/stl/cam0_R.stl
cad/out/stl/cam1_L.stl
cad/out/stl/cam1_R.stl
cad/out/stl/cam2_L.stl
cad/out/stl/cam2_R.stl
cad/out/stl/cmg_housing_L.stl
cad/out/stl/cmg_housing_R.stl
cad/out/stl/cmg_lid_R.stl
cad/out/stl/cmg_spin_motor_L.stl
cad/out/stl/cmg_spin_motor_R.stl
cad/out/stl/drum_L.stl
cad/out/stl/drum_R.stl
cad/out/stl/eq_flange_L.stl
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

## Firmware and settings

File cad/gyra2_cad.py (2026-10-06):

"""
GYRA Mk2 - split twin-crown tyre with differential drive, no CMGs, 360-degree pendulum.

What changes vs Mk1 (cad/gyra_cad.py, whose helpers this file reuses):
  * the tyre is two independently driven halves. Each half is Mk1's spherical zone with its
    crown offset outward by D_CROWN, so the robot stands on two contact patches 2*D_CROWN apart
  * each half has its own internal ring gear; the front motor drives the left half, the rear
    motor the right half. Sum of torques -> pendulum swing (drive), difference -> yaw couple
  * a slewing ring at the equator lets the halves turn relative to each other
  * CMGs and gimbal actuators removed; their mass goes into a bigger tungsten + battery bob
  * nothing of the spine sits in the pendulum's swept volume -> the pendulum can swing 360 deg
  * axle, pods and bays move outward by D_CROWN

    python cad/gyra2_cad.py [--check]                 # Mk2   -> cad/out2/
    GYRA_VARIANT=mk21 python cad/gyra2_cad.py         # Mk2.1 -> cad/out21/

Mk2.1 (root-cause fix of the sideways roll-overs, docs/08 sec. 2): crown offset 50 -> 90 mm (wider stance, roll
stiffness independent of the pendulum angle) and the worm-driven bob lean replaced by a back-drivable BLDC + ball-screw
drive (60 -> 180 deg/s, so the lean no longer rate-saturates against the ~2 s rocking mode).
"""
from __future__ import annotations

import json
import math
import os
import sys
import time

import cadquery as cq
import numpy as np
from cadquery import Vector

sys.path.insert(0, os.path.dirname(__file__))
import gyra_cad as G  # noqa: E402
from gyra_cad import (Part, box, circle_pts, cyl_dir, cyl_y, extrude_xz, extrude_yz, gear_y,  # noqa: E402
                      halfspace, hull2d, mirror_x, mirror_y, revolve_y, sector_yz, slab_y, sphere, tube_y)
from params import (AXLE_HALF, AXLE_ID, AXLE_OD, CLOCKSPRING_D, CLOCKSPRING_Y, DRIVE_MOTOR_D,  # noqa: E402
                    DRIVE_MOTOR_L, DRIVE_PINION_Z, GEAR_MODULE, GEAR_R_BODY, GEAR_R_PITCH, GEAR_Z_RING,
                    LEVEL_MOTOR_D, LEVEL_MOTOR_POS, LUG_ARC_DEG, LUG_SKEW_DEG, N_LUG_PITCH, R_OUT,
                    R_SHELL_IN, R_SHELL_OUT, R_TREAD_BASE, RIM_TRACK_R, Y_EDGE)

VARIANT = os.environ.get("GYRA_VARIANT", "mk2")
OUT2 = os.path.join(os.path.dirname(__file__), "out21" if VARIANT == "mk21" else "out2")

# ---------------------------------------------------------------------------- Mk2 parameters
D_CROWN = 90.0 if VARIANT == "mk21" else 50.0   # crown offset of each half -> patches 2*D_CROWN apart
SEAM_GAP = 2.5                   # half-gap at the equator (slewing ring sits in it)
RING_Y = (8.0, 24.0)             # |y| span of each half's internal ring gear
PULLEY_Y = (26.0, 34.0)          # |y| span of the belt pulleys
ARC_HALF2 = 60.0                 # cradle arc half-angle
ARC_R2 = (145.0, 240.0)          # cradle arc radii
BOB_R2 = (147.0, 238.0)          # bob radii
BOB_HALF2 = 22.0                 # bob angular half-width
BOB_X2 = 62.0
BOB_TRAVEL2 = 40.0               # lateral travel +-40 deg
TUNGSTEN_KG = 11.0               # W-Ni-Fe heavy alloy (17.5 g/cc)
BATTERY2_KG = 3.9                # 13S4P 21700, 936 Wh incl. BMS
LUG_ROWS_U = ((-D_CROWN + 6, 16.0, 0.0), (24.0, 88.0, 0.5), (96.0, 160.0, 0.0), (168.0, 228.0, 0.5))
BAY_Y2 = (172.0, 262.0)


def lin(s: cq.Shape, dy: float) -> cq.Shape:
    return s.translate(Vector(0, dy, 0))


# ---------------------------------------------------------------------------- tyre halves
def build_tyre_half(side: int) -> list[Part]:
    """Built for the left half in its local frame u = y - D_CROWN, then shifted (and mirrored)."""
    s = "L" if side > 0 else "R"
    grp = "tyre" + s
    u0 = -D_CROWN + SEAM_GAP
    P = []
    shell = sphere(R_SHELL_OUT).cut(sphere(R_SHELL_IN)).intersect(slab_y(u0, Y_EDGE))
    tread = sphere(R_TREAD_BASE).cut(sphere(R_SHELL_OUT)).intersect(slab_y(u0 + 3.0, Y_EDGE))
    lug_shell = sphere(R_OUT).cut(sphere(R_TREAD_BASE - 0.5))
    pitch = 360.0 / N_LUG_PITCH
    lugs = []
    for (y0, y1, phase) in LUG_ROWS_U:
        def corner(theta_deg, y, rr):
            t = math.radians(theta_deg)
            return Vector(rr * math.cos(t), y, rr * math.sin(t))
        A, B = corner(0.0, y0, R_OUT), corner(LUG_SKEW_DEG, y1, R_OUT)
        C, D = corner(LUG_ARC_DEG, y0, R_OUT), corner(LUG_ARC_DEG + LUG_SKEW_DEG, y1, R_OUT)
        mid = corner(LUG_ARC_DEG / 2 + LUG_SKEW_DEG / 2, (y0 + y1) / 2, R_OUT)
        blk = slab_y(y0, y1).intersect(halfspace(A.cross(B), mid)).intersect(halfspace(D.cross(C), mid))
        lug = lug_shell.intersect(blk)
        for k in range(N_LUG_PITCH):
            off = 0.0 if side > 0 else pitch / 2
            lugs.append(lug.rotate(Vector(0, 0, 0), Vector(0, 1, 0), (k + phase) * pitch + off))
    lugs = cq.Compound.makeCompound(lugs)
    y_in = 215.0
    rim = revolve_y([
        (RIM_TRACK_R + 6, 229.0), (RIM_TRACK_R, 232.0), (RIM_TRACK_R + 6, 235.0),
        (G.shell_in_r_at(235.0) - 0.3, 235.0), (G.shell_in_r_at(y_in) - 0.3, y_in),
        (G.shell_in_r_at(y_in) - 4, y_in), (RIM_TRACK_R + 14, 229.0)])
    flange = revolve_y([(272.0, u0), (G.shell_in_r_at(u0) - 0.3, u0),
                        (G.shell_in_r_at(u0 + 6) - 0.3, u0 + 6), (272.0, u0 + 6)])
    pieces = [("drum", shell, "gfrp", "gfrp"), ("tread_base", tread, "rubber", "pu"),
              ("lugs", lugs, "rubber", "pu"), ("rim", rim, "alu", "al"), ("eq_flange", flange, "gfrp", "gfrp")]
    for name, shp, mat, rho in pieces:
        shp = lin(shp, D_CROWN)
        P.append(Part(f"{name}_{s}", shp if side > 0 else mirror_y(shp), grp, mat, rho=rho))
    # this half's ring gear (global coordinates, axis = y)
    ring = gear_y(GEAR_Z_RING, GEAR_MODULE, RING_Y[0], RING_Y[1], internal=True, body_r=GEAR_R_BODY - 2.0)
    ring = ring.cut(tube_y(GEAR_R_PITCH + 6, GEAR_R_BODY, RING_Y[0] + 4, RING_Y[1] - 4))
    P.append(Part(f"ring_gear_{s}", ring if side > 0 else mirror_y(ring), grp, "alu_dark", rho="pa66gf"))
    if side > 0:  # equatorial slewing ring (wire-race), carried by the left half
        P.append(Part("eq_slewing_ring", tube_y(272.0, G.shell_in_r_at(D_CROWN) - 1.0, -SEAM_GAP + 0.3, SEAM_GAP - 0.3),
                      grp, "steel", rho="steel"))
    return P


# ---------------------------------------------------------------------------- spine
def build_spine2() -> list[Part]:
    P = []
    half = AXLE_HALF + D_CROWN
    P.append(Part("axle", tube_y(AXLE_ID / 2, AXLE_OD / 2, -half + 12, half - 12), "spine", "carbon", rho="cfrp"))
    for side in (+1, -1):
        for p in G.build_pod(side):
            if p.name.startswith("gimbal_bearing"):
                continue
            p.shape = lin(p.shape, side * D_CROWN)
            P.append(p)
    for side in (+1, -1):
        s = "L" if side > 0 else "R"
        br = cyl_y(45.0, 66.0, 72.0)
        if side > 0:
            lx, _, lz = LEVEL_MOTOR_POS
            br = br.fuse(extrude_xz(hull2d(circle_pts(0, 0, 30) + circle_pts(lx, lz, 30)), 66.0, 72.0))
        br = br.cut(cyl_y(AXLE_OD / 2 - 0.2, 60, 80))
        P.append(Part(f"spine_bracket_{s}", br if side > 0 else mirror_y(br), "spine", "alu", rho="al"))
        bay = box(-50, 50, BAY_Y2[0], BAY_Y2[1], -72, -28)
        strut = box(-10, 10, 164, 174, -29, 0).fuse(cyl_y(28, 164, 174)).cut(cyl_y(AXLE_OD / 2 - 0.2, 140, 190))
        if side < 0:
            bay, strut = mirror_y(bay), mirror_y(strut)
        P.append(Part(f"bay_{s}", bay, "spine", "alu_dark", mass=0.85 if side > 0 else 0.55))
        P.append(Part(f"bay_strut_{s}", strut, "spine", "alu", rho="al"))
    lx, ly, lz = LEVEL_MOTOR_POS
    P.append(Part("level_motor", cyl_y(LEVEL_MOTOR_D / 2, 50.0, 66.0, lx, lz), "spine", "motor_black", mass=0.35))
    P.append(Part("clockspring", tube_y(AXLE_OD / 2 + 0.5, CLOCKSPRING_D / 2, *CLOCKSPRING_Y), "spine", "orange", mass=0.15))
    return P


# ---------------------------------------------------------------------------- yoke
def build_yoke2() -> list[Part]:
    P = []
    (px, pz), (mx, mz) = G.drive_geometry()
    hy0, hy1 = 36.0, 42.0
    plate = cyl_y(48.0, hy0, hy1)
    for sx in (1, -1):
        wing = hull2d(circle_pts(0, 0, 48) + circle_pts(sx * mx, mz, 40) + circle_pts(sx * px, pz, 20))
        plate = plate.fuse(extrude_xz(wing, hy0, hy1))
        plate = plate.fuse(extrude_xz([(sx * 70, -112), (sx * 86, -112), (sx * 86, -172), (sx * 70, -172)], hy0, hy1))
        plate = plate.cut(extrude_xz(circle_pts(sx * 95, -60, 22), hy0 - 1, hy1 + 1))
        plate = plate.cut(extrude_xz(circle_pts(sx * 150, -150, 13), hy0 - 1, hy1 + 1))
    plate = plate.cut(cyl_y(31.0, hy0 - 1, hy1 + 1))
    P += [Part("hanger_L", plate, "yoke", "alu", rho="al"), Part("hanger_R", mirror_y(plate), "yoke", "alu", rho="al")]
    brg = tube_y(AXLE_OD / 2 + 0.2, 31.0, hy0 - 6, hy1)
    P += [Part("hub_bearing_L", brg, "yoke", "steel", rho="steel"), Part("hub_bearing_R", mirror_y(brg), "yoke", "steel", rho="steel")]
    lgear = gear_y(46, 3.0, hy1, hy1 + 6, internal=False, bore=AXLE_OD / 2 + 2).cut(tube_y(AXLE_OD / 2 + 14, 58.0, hy1 - 1, hy1 + 7))
    P.append(Part("level_gear", lgear, "yoke", "steel", rho="pom"))

    ax0, ax1 = 75.0, 81.0
    arc = extrude_yz(sector_yz(ARC_R2[0], ARC_R2[1], -ARC_HALF2, ARC_HALF2), ax0, ax1)
    P += [Part("arc_plate_F", arc, "yoke", "alu", rho="al"), Part("arc_plate_B", mirror_x(arc), "yoke", "alu", rho="al")]
    rails = []
    for (r0, r1) in ((ARC_R2[0] + 6, ARC_R2[0] + 14), (ARC_R2[1] - 14, ARC_R2[1] - 6)):
        rl = extrude_yz(sector_yz(r0, r1, -ARC_HALF2 + 2, ARC_HALF2 - 2), ax0 - 5, ax0)
        rails += [rl, mirror_x(rl)]
    P.append(Part("bob_rails", cq.Compound.makeCompound(rails), "yoke", "steel", rho="steel"))
    P.append(Part("lean_rack", extrude_yz(sector_yz(192, 198, -ARC_HALF2 + 4, ARC_HALF2 - 4), ax0 - 8, ax0), "yoke", "steel", rho="steel"))

    def train(sign):   # front motor -> left half (+y), rear motor -> right half (-y)
        x_m, x_p = sign * mx, sign * px
        mot = cyl_y(DRIVE_MOTOR_D / 2, hy1, hy1 + DRIVE_MOTOR_L, x_m, mz)
        bell = cyl_y(DRIVE_MOTOR_D / 2 - 6, hy1 + DRIVE_MOTOR_L, hy1 + DRIVE_MOTOR_L + 6, x_m, mz)
        p_small = cyl_y(12.0, *PULLEY_Y, x_m, mz)
        p_big = cyl_y(24.0, *PULLEY_Y, x_p, pz)
        shaft_m = cyl_y(4.0, PULLEY_Y[0], hy1, x_m, mz)
        outer = hull2d(circle_pts(x_m, mz, 13.6) + circle_pts(x_p, pz, 25.6))
        inner = hull2d(circle_pts(x_m, mz, 12.1) + circle_pts(x_p, pz, 24.1))
        belt = extrude_xz(outer, PULLEY_Y[0] + 1, PULLEY_Y[1] - 1).cut(extrude_xz(inner, PULLEY_Y[0], PULLEY_Y[1]))
        pinion = gear_y(DRIVE_PINION_Z, GEAR_MODULE, RING_Y[0] + 1, RING_Y[1] - 1, x_p, pz, bore=4)
        shaft_p = cyl_y(6.0, -hy1, hy1, x_p, pz)
        parts = [mot.fuse(bell), p_small.fuse(shaft_m), p_big, belt, pinion]
        if sign < 0:
            parts = [mirror_y(v) for v in parts]
        t = "F" if sign > 0 else "B"
        mot, pm, pb, belt, pinion = parts
        return [Part(f"drive_motor_{t}", mot, "yoke", "motor_black", mass=0.90),
                Part(f"pulley_m_{t}", pm, "yoke", "alu", rho="al"), Part(f"pulley_p_{t}", pb, "yoke", "alu", rho="al"),
                Part(f"belt_{t}", belt, "yoke", "rubber", mass=0.03), Part(f"pinion_{t}", pinion, "yoke", "steel", rho="steel"),
                Part(f"pinion_shaft_{t}", shaft_p, "yoke", "steel", rho="steel")]
    P += train(+1) + train(-1)
    for sy in (1, -1):
        esc = box(-30, 30, 23, 35, -105, -62)
        P.append(Part(f"esc_{'L' if sy > 0 else 'R'}", esc if sy > 0 else mirror_y(esc), "yoke", "pcb", mass=0.15))
    # Mk2: the compute module rides on the pendulum (extra ballast, better m*L)
    P.append(Part("compute_pendulum", box(-45, 45, -20, 20, -140, -110), "yoke", "alu_dark", mass=0.7))
    return P


# ---------------------------------------------------------------------------- bob
def build_bob2() -> list[Part]:
    P = []
    w = extrude_yz(sector_yz(206.0, BOB_R2[1], -BOB_HALF2, BOB_HALF2), -BOB_X2 + 2, BOB_X2 - 2)
    batt = extrude_yz(sector_yz(BOB_R2[0] + 3, 203.0, -BOB_HALF2 + 1.5, BOB_HALF2 - 1.5), -BOB_X2 + 4, 30.0)
    if VARIANT == "mk21":        # BLDC + ball-screw lean drive: back-drivable, 180 deg/s
        worm = cq.Solid.makeCylinder(17.0, 30.0, Vector(30.0, 0, -180.0), Vector(1, 0, 0))
    else:                        # worm drive: self-locking, 60 deg/s
        worm = cq.Solid.makeCylinder(15.0, 24.0, Vector(34.0, 0, -180.0), Vector(1, 0, 0))
    sec = sector_yz(BOB_R2[0], BOB_R2[1], -BOB_HALF2 - 2, BOB_HALF2 + 2)
    carriage = [extrude_yz(sec, BOB_X2, BOB_X2 + 4), extrude_yz(sec, -BOB_X2 - 4, -BOB_X2)]
    pin = cyl_dir(10.0, 8.0, Vector(BOB_X2 + 4, 0, -195.0), Vector(1, 0, 0))
    P.append(Part("bob_tungsten", w, "bob", "lead", mass=TUNGSTEN_KG))
    P.append(Part("bob_battery", batt, "bob", "battery", mass=BATTERY2_KG))
    P.append(Part("bob_lean_drive" if VARIANT == "mk21" else "bob_worm_motor", worm, "bob", "motor_black",
                  mass=0.45 if VARIANT == "mk21" else 0.35))
    P.append(Part("bob_carriage", cq.Compound.makeCompound(carriage), "bob", "alu_dark", rho="al"))
    P.append(Part("bob_lean_pinion", pin, "bob", "steel", rho="steel"))
    return P


def build_all2() -> list[Part]:
    t0 = time.time()
    parts = build_tyre_half(+1) + build_tyre_half(-1) + build_spine2() + build_yoke2() + build_bob2()
    print(f"built {len(parts)} parts in {time.time() - t0:.1f}s")
    return parts


def explode2(p: Part) -> Vector:
    n = p.name
    side = 1 if n.endswith("_L") else (-1 if n.endswith("_R") else 0)
    if p.group in ("tyreL", "tyreR"):
        return Vector(0, (1 if p.group == "tyreL" else -1) * 300, 0)
    if n.startswith(("pod_", "lidar", "cam", "lens", "gnss", "led_ring", "rollers", "axle_flange")):
        return Vector(0, side * 560, 0)
    if p.group == "bob":
        return Vector(0, 0, -330)
    if n.startswith(("bay", "spine_bracket")):
        return Vector(0, side * 160, 0)
    return Vector(0, 0, 0)


ALLOWED2 = {frozenset(("pinion_F", "ring_gear_L")), frozenset(("pinion_B", "ring_gear_R")),
            frozenset(("bob_lean_pinion", "lean_rack")), frozenset(("eq_slewing_ring", "eq_flange_R"))}


def main():
    os.makedirs(OUT2, exist_ok=True)
    parts = build_all2()
    mp = {p.name: {**G.mass_props(p), "group": p.group} for p in parts}
    bodies = {g: G.combine([mp[p.name] for p in parts if p.group == g]) for g in sorted({p.group for p in parts})}
    robot = G.combine(list(mp.values()))
    json.dump({"robot": robot, "bodies": bodies, "parts": mp}, open(os.path.join(OUT2, "mass_properties.json"), "w"), indent=1)
    for g, b in bodies.items():
        print(f"  {g:6s} m={b['mass']:6.2f} kg  com={np.round(b['com_mm'], 1)}")
    print(f"  ROBOT  m={robot['mass']:6.2f} kg  com={np.round(robot['com_mm'], 1)}")
    G.OUT = OUT2
    G.explode_offset = explode2
    man = G.export(parts)
    json.dump(man, open(os.path.join(OUT2, "manifest.json"), "w"), indent=1)
    G.export_step(parts, os.path.join(OUT2, "gyra_mk2.step"))
    print("exported STEP + STL")
    if "--check" in sys.argv:
        G.ALLOWED = ALLOWED2
        report = []
        for pt in (0, 60, -60, 120, -120, 180):
            for bb in (0, -40, 40):
                hits = G.interference(G.pose(parts, pitch=pt, bob=bb))
                report.append({"pitch": pt, "bob": bb, "hits": hits})
                print(f"pose pitch={pt:4} bob={bb:4}: {len(hits)} hits {hits[:5] if hits else 'CLEAR'}", flush=True)
        json.dump(report, open(os.path.join(OUT2, "interference_report.json"), "w"), indent=1)


if __name__ == "__main__":
    main()

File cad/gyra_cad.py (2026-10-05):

"""
GYRA Mk1 - parametric CAD model (CadQuery / OpenCascade).

Builds every part of the robot, grouped by kinematic body:

    tyre      - GFRP drum halves, PU tread + lugs, rim V-track rings, equatorial ring gear
    spine     - axle, sensor pods (plates, shields, LiDARs, cameras, rollers), brackets, bays
    yoke      - pendulum pitch body: hanger plates, cradle arc plates, rails, drive motors,
                belts, pinions (rotates about +y by `pitch`)
    bob       - battery + lead ballast carriage (rotates about +x by `bob` on the yoke)
    cmgL/cmgR - CMG gimbal housings (rotate about y through the CMG centre by `gimbal`)
    flyL/flyR - CMG flywheels (inside the gimbal housings)

Usage:
    python cad/gyra_cad.py                 # build, export STEP/STL/GLB + mass properties
    python cad/gyra_cad.py --check         # also run the multi-pose interference check
"""
from __future__ import annotations

import json
import math
import os
import sys
import time
from dataclasses import dataclass, field

import cadquery as cq
import numpy as np
from cadquery import Vector
from OCP.BRepGProp import BRepGProp
from OCP.GProp import GProp_GProps

sys.path.insert(0, os.path.dirname(__file__))
from params import *  # noqa: E402,F401,F403

OUT = os.path.join(os.path.dirname(__file__), "out")

# densities in kg/mm^3
RHO = {
    "al": 2.70e-6, "steel": 7.85e-6, "lead": 11.34e-6, "pu": 1.15e-6,
    "gfrp": 1.85e-6, "pa12": 1.01e-6, "brass": 8.50e-6,
    "pom": 1.41e-6, "pa66gf": 1.36e-6, "cfrp": 1.55e-6,
}


@dataclass
class Part:
    name: str
    shape: cq.Shape
    group: str
    material: str              # render material key
    rho: str | None = None     # density key, or None if mass given
    mass: float | None = None  # kg override (COTS parts)
    meta: dict = field(default_factory=dict)


# ---------------------------------------------------------------------------
# geometry helpers
# ---------------------------------------------------------------------------
def z_to_y(s: cq.Shape) -> cq.Shape:
    """Rotate a shape built around +z so that its axis becomes +y."""
    return s.rotate(Vector(0, 0, 0), Vector(1, 0, 0), -90)


def revolve_y(profile_ry: list[tuple[float, float]]) -> cq.Shape:
    """Revolve a closed (r, y) profile about the global y axis."""
    wp = cq.Workplane("XZ").polyline(profile_ry).close().revolve(360, (0, 0, 0), (0, 1, 0))
    return z_to_y(wp.val())


def cyl_y(r: float, y0: float, y1: float, x: float = 0.0, z: float = 0.0) -> cq.Shape:
    return cq.Solid.makeCylinder(r, y1 - y0, Vector(x, y0, z), Vector(0, 1, 0))


def tube_y(r_in: float, r_out: float, y0: float, y1: float, x=0.0, z=0.0) -> cq.Shape:
    return cyl_y(r_out, y0, y1, x, z).cut(cyl_y(r_in, y0 - 1, y1 + 1, x, z))


def cyl_dir(r: float, h: float, base: Vector, d: Vector) -> cq.Shape:
    return cq.Solid.makeCylinder(r, h, base, d)


def box(x0, x1, y0, y1, z0, z1) -> cq.Shape:
    return cq.Solid.makeBox(x1 - x0, y1 - y0, z1 - z0, Vector(x0, y0, z0))


def sphere(r: float, c=(0, 0, 0)) -> cq.Shape:
    return cq.Solid.makeSphere(r, Vector(*c), angleDegrees1=-90, angleDegrees2=90)


def slab_y(y0: float, y1: float, big: float = 2000) -> cq.Shape:
    return box(-big, big, y0, y1, -big, big)


def extrude_xz(pts_xz, y0, y1) -> cq.Shape:
    """Polygon in the x-z plane extruded along +y from y0 to y1."""
    wp = cq.Workplane("XZ", origin=(0, 0, 0)).polyline(pts_xz).close().extrude(-(y1 - y0))
    return wp.val().translate(Vector(0, y0, 0))


def extrude_yz(pts_yz, x0, x1) -> cq.Shape:
    """Polygon in the y-z plane extruded along +x from x0 to x1."""
    wp = cq.Workplane("YZ").polyline(pts_yz).close().extrude(x1 - x0)
    return wp.val().translate(Vector(x0, 0, 0))


def sector_yz(r0, r1, a0_deg, a1_deg, n=40):
    """Annular sector in the y-z plane, angle measured from -z towards +y."""
    a = np.radians(np.linspace(a0_deg, a1_deg, n))
    outer = [(r1 * math.sin(t), -r1 * math.cos(t)) for t in a]
    inner = [(r0 * math.sin(t), -r0 * math.cos(t)) for t in a[::-1]]
    return outer + inner


def circle_pts(cx, cz, r, n=48, a0=0.0, a1=2 * math.pi):
    return [(cx + r * math.cos(t), cz + r * math.sin(t)) for t in np.linspace(a0, a1, n, endpoint=False)]


def hull2d(pts):
    from scipy.spatial import ConvexHull
    p = np.array(pts)
    h = ConvexHull(p)
    return [tuple(p[i]) for i in h.vertices]


def gear_profile(z_teeth: int, module: float, internal: bool):
    """Trapezoidal-tooth approximation of an involute gear outline (x-y plane)."""
    rp = module * z_teeth / 2
    if internal:
        r_tip, r_root = rp - module, rp + 1.25 * module
    else:
        r_tip, r_root = rp + module, rp - 1.25 * module
    pts = []
    p = 2 * math.pi / z_teeth
    for k in range(z_teeth):
        a = k * p
        # tooth (material): narrow at tip, wide at root
        pts += [
            (r_root, a - 0.30 * p), (r_tip, a - 0.16 * p),
            (r_tip, a + 0.16 * p), (r_root, a + 0.30 * p),
        ]
    if internal:   # gap between teeth is at the root for internal gears -> swap
        pts = []
        for k in range(z_teeth):
            a = k * p
            pts += [
                (r_tip, a - 0.22 * p), (r_root, a - 0.10 * p),
                (r_root, a + 0.10 * p), (r_tip, a + 0.22 * p),
            ]
    return [(r * math.cos(t), r * math.sin(t)) for r, t in pts]


def gear_y(z_teeth, module, y0, y1, cx=0.0, cz=0.0, internal=False, body_r=None, bore=0.0):
    """Gear with its axis along y, centred at (cx, ., cz)."""
    prof = gear_profile(z_teeth, module, internal)
    teeth = cq.Workplane("XY").polyline(prof).close().extrude(y1 - y0).val()
    if internal:
        disk = cq.Solid.makeCylinder(body_r, y1 - y0, Vector(0, 0, 0), Vector(0, 0, 1))
        g = disk.cut(teeth)
    else:
        g = teeth
        if bore > 0:
            g = g.cut(cq.Solid.makeCylinder(bore, y1 - y0 + 2, Vector(0, 0, -1), Vector(0, 0, 1)))
    g = z_to_y(g)                    # axis now +y, spanning y in [0, y1-y0]
    return g.translate(Vector(cx, y0, cz))


def halfspace(n: Vector, inside: Vector, big: float = 1500.0) -> cq.Shape:
    """Half-space bounded by the plane through the origin with normal n, containing `inside`."""
    n = n.normalized()
    if n.dot(inside) < 0:
        n = -n
    xd = n.cross(Vector(0, 1, 0)) if abs(n.y) < 0.9 else n.cross(Vector(1, 0, 0))
    pl = cq.Plane(origin=(0, 0, 0), xDir=xd.normalized(), normal=n)
    return cq.Workplane(pl).rect(2 * big, 2 * big).extrude(big).val()


def mirror_y(s: cq.Shape) -> cq.Shape:
    return s.mirror("XZ")


def mirror_x(s: cq.Shape) -> cq.Shape:
    return s.mirror("YZ")
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

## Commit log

2026-10-05 GYRA Mk1: RT-G teardown, novel spherical robot CAD, sizing and MuJoCo sim
    - docs: how the RT-G / RotunBot works (from the ZJU paper + sources), GYRA Mk1
    design spec, simulation report
    - cad: parametric CadQuery model (89 parts) with STEP/STL/GLB export, CAD-derived
    mass properties and a 45-pose B-rep interference check (0 hits)
    - calc: closed-form sizing from CAD mass properties
    - sim: MuJoCo model generated from CAD inertias; drive, lean-steer with/without
    CMG damping, turn-in-place, hill-climb scenarios
    - render: Blender Cycles pipeline, call-out annotation, three.js viewer
    Claude-Session: https://claude.ai/code/session_01FVUJA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
    [arc_plate_B.stl, arc_plate_F.stl, axle.stl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]
2026-10-05 cad: GYRA Mk2 - split twin-crown tyre, differential drive, 360-deg pendulum, no CMGs
    Interference-free over pitch 0/+-60/+-120/180 x lean 0/+-40 (B-rep check).
    Claude-Session: https://claude.ai/code/session_01FVUJAdJD2h6oj6JGqR1ohR
    [arc_plate_B.stl, arc_plate_F.stl, axle.stl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]
2026-10-05 sim: Mk2 MuJoCo model from CAD inertias, motor torque-speed model, classical baseline + benchmark
    Turn in place 163-258 deg/s (Mk1 CMG ~9 deg/s), 14 deg grade, 8.5 m/s stable,
    sensor pitch 0.39 deg. High-speed turning with the classical loop is oscillatory
    (target for the learned policy).
    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
2026-10-05 rl: asymmetric-PPO stack - Mk2 locomotion env (sensor-realistic actor, privileged critic, domain randomisation, pushes), vector env, PPO, nav env with pod-LiDAR blind wedge, stereo depth and drifting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
    [progress.csv]
2026-10-05 rl: reward/curriculum fixes, eval harnesses (loco vs classical, nav vs VFH baseline), Mk2 render support
    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
    [progress.csv]
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2026-10-05 rl: locomotion milestone @3.9M steps - learned residual policy survives the 6 m/s turn that makes the classical loop fall, 8% vs 67% falls under randomised dynamics+pushes, 1.8x lower yaw error
    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
    [progress.csv]
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2026-10-06 rl: nav milestone - 79% vs 72% success, 2% vs 11% collisions, 1.6x faster than VFH baseline (100 maps)
    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
    [progress.csv]
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2026-10-06 rl: navigation path figure (learned vs VFH), odometry-drift failure mode documented
    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
2026-10-06 Nav world: compile obstacles as convex mesh geoms every episode
    Moving/resizing primitive geoms of the static world body at runtime left
    MuJoCo's world-body BVH and geom AABBs stale, so tyre-obstacle contacts
    were silently missed (only walls collided). Every reset now samples the
    layout and compiles a fresh world in which each obstacle and wall is a
    convex mesh geom; the same vertices drive collision, LiDAR/depth rays
    and rendering. Probe: 15/15 head-on runs now register a collision.
    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
2026-10-06 Locomotion v2: terrain + disturbance env, history-encoder/estimator PPO with symmetry loss
    - sim/terrain.py: procedural heightfields (hills, rough, curbs/ditches, ramps, smoothly
    blended mixed), 60 m patch, 0.15 m cells
    - build_xml2: heightfield terrain, tyre radius, spine payload, full gravity vector
    - rl/loco2_env.py: world recompiled every episode; friction 0.25-1.2 with mid-episode
    surface change, slope, payload, mass/CoM, tyre wear, per-motor strength, torque
    noise, latency, pushes + yaw kicks, wind with gusts, IMU bias/misalignment/glitches;
    per-env adaptive curriculum; every reward term logged
    - rl/ppo2.py: TCN history encoder (1 s), concurrent estimator head, left/right
    sym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
2026-10-06 Navigation v2 env + trainer; renderer builds the world from compiled collision geometry
    - rl/nav2_env.py: clutter / forest / rooms / maze / mixed worlds compiled per episode
    on locomotion-v2 terrain, pedestrians as mocap mesh bodies, geodesic-progress
    reward (Dijkstra on the inflated occupancy grid), LiDAR sector blindness, spurious
    returns, depth blackout/drops, odometry drift; frozen locomotion v2 policy runs
    inside (its estimator output is part of the navigation observation)
    - rl/ppo2.py: NavActor (circular 1-D conv LiDAR, 2-D conv depth), PermMirror
    - sim/terrain.py: height lookup reproduces MuJoCo's heightfield vertex grid and
    triangulation exactly (max |ray - lookup| 0.005 mm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
2026-10-06 Nav v2: global planner subgoal on a stale prior map (or none); navigation benchmark
    The learned navigator becomes the local planner/controller of a production-style
    stack: in 70 % of episodes a prior map (walls + 60-100 % of the free-standing
    obstacles, never pedestrians) feeds a Dijkstra planner whose 2.5 m look-ahead point
    is an observation; otherwise the subgoal is the goal itself.
    rl/eval_nav2.py: 12 fixed-seed scenarios (families, no/stale map, fast pedestrians,
    blind LiDAR sector, dead depth camera, dust, all at once) on rough ground with
    disturbances; learned vs VFH (same sensors + subgoal) vs privileged oracle.
    Claude-Session: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
2026-10-06 Loco v2: fix CSV header dropping episode metrics; --level0 for resumes; safer stop script
    The progress.csv header was taken from iteration 1, before any episode had ended,
    so ep_* and per-terrain fall columns were silently dropped. Training resumed from
    the 4M-step checkpoint with the curriculum at level 0.5.
    Quick check at 4M (6 episodes/scenario): v2 already has the lowest speed error and
    spine tilt on flat/ice/pushes, but still falls more than the baselines at 8 m/s and on
    rough ground (curriculum had reached ~5.6 m/s).
    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
    [progress_0-4M.csv]
2026-10-06 Root-cause analysis of locomotion falls; Mk2.1 hardware; feasible-reference reward; ADR
    Diagnosis (rl/diagnose_falls.py): every fall of both the classical controller and the
    v2 policy is a sideways roll, not drive saturation. Causes, measured:
    - the pendulum supplies both longitudinal force and (via the low CoM) roll stiffness:
    holding a 12 deg incline or braking from 6 m/s swings it to 45-70 deg and spends the
    roll stability (growing roll oscillation, then pod strike)
    - the only roll actuator, the worm-driven bob (60 deg/s), saturates and lags the ~2 s
    rocking period, so it pumps energy into the oscillation
    - the sim's failure limit (roll > 63 deg) was not physical, and full-sphere ty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
2026-10-06 CAD: Mk2.1 generated (cad/out21): 90 mm crown offset, ball-screw lean drive; 45.83 kg, 0 interferences in 18 poses
    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
    [arc_plate_B.stl, arc_plate_F.stl, axle.stl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]
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2026-10-06 Locomotion v3 final: 15M-step checkpoint (CAD-exact Mk2.1: 8/384 falls = 2.08 %, tilt 0.20 deg)
    15M vs 20M on the CAD-exact Mk2.1 model, 24 episodes x 16 scenarios: 8 vs 9 falls,
    tilt 0.198 vs 0.221 deg, speed RMSE 0.341 vs 0.328 m/s -> plateau; training stopped and
    15M selected. Remaining failures are dominated by 350 N lateral pushes (12.5 %), which
    exceed the roll capacity of the hardware. Checkpoints now also store the ADR state.
    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
    [progress_0-20M.csv]
2026-10-06 Nav v2: footprint derived from hardware (Mk2.1 is 0.393 m half-width, planner assumed 0.36); oversampled LiDAR
    Root causes found from the 2M-step benchmark, where even the privileged oracle
    collided in 19-69 % of episodes:
    - every oracle collision was a near-zero-speed side scrape (tyre + pod against a wall):
    the Mk2.1 widening (crown 90 mm) had not been propagated to navigation, so paths
    were planned ~2 cm from walls. The footprint is now derived from the hardware config,
    with an 8 cm planning margin (oracle success: mixed 50 -> 80 %, forest 69 -> 90 %)
    - a 72-beam scan (5 deg bins) misses 5 cm poles beyond ~1 m; each beam now reports the
    minimum of 4 rays across its bin, as a 2-D s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
    [progress_run1.csv]
2026-10-06 Locomotion v3.1: precision terms (leaky integrated heading + along-track error, fine kernels)
    Root cause of the remaining navigation collisions: the v3 policy has a -0.08..-0.10 rad/s
    yaw-rate bias even when told to hold still (28 deg and 35 cm of drift in 6 s, 1.6 m
    sideways after 3 m of creeping), while sideslip is negligible. The sigma = 0.5 tracking
    kernels made such small persistent errors essentially free. Leaky integrals of the
    heading and along-track errors (0.2/s leak) turn any bias into a growing error, plus
    sigma = 0.1 fine kernels. Fine-tuned from the 15M checkpoint; warm start now copies
    overlapping blocks when observation sizes grow (critic +2 inputs).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
2026-10-06 Loco v3.1: penalise all spine roll and the residual magnitude
    Diagnosis: during 'hold still' the policy kept its bob action pinned at +1 (bob leaned
    ~28 deg to one side) with a constant differential residual. Because the last action is
    observed, leaned-left and leaned-right are self-reinforcing modes that still satisfy the
    symmetry loss; the reward ignored roll below 8.6 deg and the residual was free. The
    lean shifts the CoM and produces the slow yaw drift (hold: 12-18 deg in 6 s, creep: up
    to 38 deg). Fix at the task level: tilt = -pitch^2 - 0.5 roll^2 (a level sensor platform
    in both axes) and -0.02 |a|^2 (deviate from the classical loop only when it pays).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
2026-10-06 Nav planner: costmap-weighted Dijkstra (paths keep to corridor/door centres); plain-length field for SPL
    Remaining oracle collisions were turns past door jambs and room-wall corners with
    clearance shrinking to zero: shortest paths over a hard inflation boundary graze
    corners. Edge cost now rises up to 5x within 0.6 m of the footprint touching anything.
    Oracle (v3 low-level), 10 episodes: maze 10/10, thin-pole forest 10/10; with the
    more precise v3.1 low-level: mixed 9/10. Rooms with 1.0 m doors stay hard (3-4/10):
    10.7 cm per side for the 786 mm-wide Mk2.1.
    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
2026-10-06 Locomotion v3.1 final (9M): robustness 7/384 falls (1.82 %), spin heading error 31 -> 0.8 deg
    CAD-exact Mk2.1, 24 episodes x 16 scenarios: v3 8 falls, v3.1 7 falls; speed RMSE
    0.341 -> 0.328. Precision (flat, nominal): spin-in-place heading error 30.8 -> 0.8 deg,
    creep heading drift 26.7 -> 12.7 deg, creep lateral 88 -> 44 cm, spin displacement
    21 -> 10 cm, stop overrun 63 -> 57 cm.
    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
2026-10-06 Nav v2 run-2 logs (0-4M, footprint fix) kept for the record
    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
    [progress_run2.csv]
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2026-10-12 Navigation v2 final: 6M-step checkpoint (58.9 % success, 20.3 % collisions; VFH 32.3 / 61.5 %)
    7M: 60.4 % success but 25.5 % collisions -> plateau; 6M selected (fewer collisions).
    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
2026-10-12 Video: GYRA Mk2.1 autonomous mission, third-person chase camera (32 s, 960x540)
    Every obstacle, wall, pole, pedestrian and the ground are built from the geometry read
    back from the compiled MuJoCo model; geometry check over 3810 MuJoCo probe rays
    re-cast in the Blender scene: max error 0.037 mm, none over 1 mm
    (media/mission2_geometry_check.json).
    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
2026-10-12 Phase 0 navigation failure taxonomy; phase 1 building blocks (local map, safety filter, sysid)
    Taxonomy (nav 6M, 12 scenarios x 32 episodes, pod contacts counted): success 56.8 %,
    collisions 26.3 % (92 static / 9 pedestrian, 93 at-fault), timeouts 16.9 %.
    83 of 101 colliding obstacles were in the masked LiDAR scan during the last second
    and 11 more were seen only by depth: seen-but-not-avoided, the class a safety filter
    removes. 67 were side contacts (corner cutting). Timeouts: median 7.6 m left,
    27 % of the time stopped, ~28 yaw-rate reversals (memoryless dithering; worst without
    a map).
    - rl/local_map.py: rolling odometry-frame log-odds grid fusing masked LiDAR and depth;
    free-space evid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
2026-10-12 Phase 1 safety layer: LIO odometry model, dense-LiDAR local map, unknown-as-obstacle filter
    Findings driving each change (all measured):
    - map false positives 27 % with wheel+gyro odometry vs 4 % with the true pose: drift,
    not sensing, broke the map. GYRA carries two 3-D LiDARs + IMU, so the production
    stack runs LiDAR-inertial odometry; modelled as 0.5 %/m drift + 0.1 deg/m heading
    (map false positives -> 4.5 %). Wheel+gyro kept as a 'LiDAR odometry lost' scenario.
    - a correlative scan matcher on the 72-beam masked scan did not beat odometry; removed
    - state-dependent braking identified (pendulum must swing through before braking)
    - thin poles flicker at 1.25 deg ray spacing: the map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
2026-10-12 Safety filter: fix deadlocks and chatter found by tracing shielded episodes
    A/B on 4 scenarios x 16 episodes: shield cut collisions 30 % -> 9 % but timeouts rose to 70 %.
    Traces showed three root causes:
    - forward blind wedge (Mk2.1 pods cannot see 2.25 m straight ahead past the tyre): with the depth
    camera dead the area ahead stayed unknown at spawn and every motion was inadmissible. Spawn disc
    (start clearance > 0.75 m by construction) is now prior-known free.
    - free evidence decayed to unknown after ~12 s standing still: only occupied evidence fades now
    (pedestrian ghosts still clear; a faded cell is unknown, still blocked for safety).
    - recovery inside the guard band could not rank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
2026-10-12 Shielded training option; field-condition error envelope for the safety filter
    - nav2_env: correction penalty (SHIELD_COST per unit of filter correction); the actor observes the
    command actually executed; train_nav2 --shield logs the intervention rate
    - shielded diagnosis (4 scenarios x 16 episodes, same policy): success 28 -> 66 %, collisions 9 %,
    timeouts 70 -> 25 % after the deadlock/chatter fixes. Remaining collisions all low-speed (median
    0.18 m/s) with the obstacle already in the map: the identified response model was fitted in calm
    conditions; under rough ground + wind + payload its 1 s path error is 12-23 cm p95 even at low speed.
    - sysid_low: field condition (benchmark distu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
2026-10-12 Safety filter: field error envelope applied over the reaction phase; sysid.json re-identified (field condition, error table)
    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
2026-10-12 3-D LiDAR model for the local map; collision timeline forensics
    - the map scan is now cut from 3-D returns: horizontal ring + 8 downward rings whose ground bands tile
    0.4-6 m, so every obstacle taller than 0.10 m is returned (the Mid-360s sweep densely in elevation).
    The single hub-height plane missed low obstacles in every test world (4-35 rays each, some < 1 m away).
    Rings cast against obstacles only, returns below the terrain surface rejected: 1 ms per scan.
    - benchmark with the field error envelope: collisions unchanged at 9.4 %, timeouts 16 -> 20; the
    low-level brakes normally when told to stop while turning (0.4 m/s -> stops within 0.41 m, field)
    - diagnose_nav: map snapshots o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
2026-10-12 Position hold at rest; braking must clear both the arc and the straight path
    Collision timeline (8 collisions, 64 shielded episodes): every obstacle was in the map >= 3 s before
    contact - perception is not the cause. Two causes remain:
    - creep: commanded to stop, the robot wobbles at 0.1-0.3 m/s under rough ground + wind and drifts
    into the obstacle (up to 0.4 m in 5 s). Stop now means stay here: once at rest, a 10 Hz outer loop
    on the along-track displacement from the rest point (gain 2/s; 0.5-4 tested) bounds the excursion
    to 0.13-0.17 m worst case.
    - late braking at 1.7-2.3 m/s: the backup stop was assumed to follow the commanded arc; when the yaw
    rate dies while braking the robot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
2026-10-12 Safety filter: anisotropic error envelope (cross-track inflates, along-track shifts)
    The privileged oracle with the filter: 1.6 % collisions but 12/16 timeouts in rooms with 1.0 m doors
    (10.7 cm per side for the 0.786 m robot). The isotropic field error (6 cm at 0.3 s even at low speed)
    made doors inadmissible, yet that error is almost all along-track; cross-track p95 is 2 cm at 0.3 s
    (sysid_low --arcs-only now measures both). The filter now inflates the footprint by the cross-track
    error and checks the path shifted ahead/behind by the along-track error. Door test: before, only a
    crawl (0.1 m/s) exactly centred; now up to 0.8 m/s centred and +-5 cm off-centre at 0.2 m/s.
    Shielded fine-tuning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
2026-10-12 Local map: distances to the mean hit point of each cell, not the cell centre
    Oracle + filter still timed out in 11/16 door episodes. The map's 1.0 m doors were 0.90-0.95 m wide:
    hits marked on 5 cm cells, distances taken to cell centres, and 2 cm range noise pushing hits into the
    next cell grow every surface by 2.5-5 cm. Each cell now keeps the running mean of its hit points (LiDAR
    and depth); clearance is the exact distance from the query point to the nearest blocked cell's mean hit
    point (EDT feature indices). Stuck door state: slack -0.051 -> -0.001. Oracle 4 scenarios x 16: success
    70 -> 72 %, collisions 1.6 %, rooms timeouts 11 -> 8; the rest is the crude oracle approaching doors
    off-ax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
2026-10-12 Shielded training: the navigator observes the filter's safe-speed envelope
    First shielded fine-tune (0.9 M steps) was reward hacking: success 81 -> 45 %, timeouts 0 -> 43 %,
    reward up, correction rate flat at ~0.6. The filter corrected 60 % of steps from the start for reasons
    the navigator cannot see (map memory, blind wedge, braking envelope; straight-ahead speed is capped at
    ~2.25 m/s by the 4.8 m map radius), so the correction penalty could only teach it to stand still.
    - actor/critic observation + 7: per yaw rate, the fastest forward speed with every slower one admissible
    (computed after the map update; mirrored w -> -w)
    - correction penalty 1.0 -> 0.3; train_nav2 --init warm-starts ac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
2026-10-12 Near-field ground cameras and a look-around primitive: the robot can start from rest
    Shield-trained navigator at 1 M steps: 0 collisions in 64 benchmark episodes (unshielded: 30 %), success
    61 %, timeouts 39 %, half of them never leaving the start: forward was blocked by the unknown wedge ahead
    of the tyre (pod LiDARs blind to 2.25 m; depth camera sees the floor only beyond 1.6 m), and standing
    still never reveals it.
    - the pods' ground/near-field cameras (Mk1 design) are modelled: floor points one pod can see past the
    tyre (crown spheres clipped at the tyre half-width: 91 % of the 0.3-1.5 m floor, centreline from 1.14 m,
    matching the design doc's 1.1-2.3 m), sight lines cast per pod; fr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
2026-10-12 Shield-trained navigator (2 M steps; plateau since 1 M): benchmark 72 % success, 1.6 % collisions
    64 shielded benchmark episodes (mixed / rooms 1.0 m doors / thin-pole forest / depth camera dead):
    nav v2 without filter 66 % success, 30 % collisions
    nav v2 + filter 50 % 4.7 %
    shield-trained 1 M 77 % 1.6 %
    shield-trained 2 M (this) 72 % 1.6 % (difference to 1 M within noise; training curve flat)
    Remaining failures are timeouts with heavy dithering (41 yaw reversals, stopped 45 %): the navigator sees
    0.2 s of scans but not the map the filter uses -> phase 2 gives it the map.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
2026-10-12 Phase 2: the navigator sees the local map (egocentric CNN branch)
    Shielded training plateaued (1-2 M steps) with timeouts that dither in front of doors and obstacles:
    the navigator saw 0.2 s of scans but not the map the filter uses. Its observation now ends with the
    filter's map, robot-centred and heading-aligned: 48 x 48 cells of 0.15 m (7.2 m), channels occupied
    evidence and known free (unknown = both 0). NavActor gets a map CNN branch whose features join the policy
    MLP after the existing inputs, so the shield-trained policy warm-starts unchanged (actions match to 1e-3).
    Mirror symmetry flips the map rows (robot-frame y). Training run: rl/runs/nav3.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
2026-10-12 Filter/map: reverse look-around, sampling holes, ground-segmented depth; stall analyser; geodesic MPC teacher
    The map-aware navigator did not improve under RL (flat 0.9 M steps). A privileged teacher (rl/teacher.py:
    sampling MPC on the true geodesic cost-to-go, only filter-admissible commands) reached only 61 % under the
    shield (31 % in door rooms), so the stalls were not a navigator problem. rl/diagnose_stuck.py classifies
    every stall by what blocks the least progress command the teacher wants:
    - 86 % of stalls were reverses blocked by unknown space (the wedge exists behind the tyre too, and backing
    out to re-approach a gap is the move a good navigator wants): look-around now also serves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
2026-10-12 Deployable MPC navigator: 90.6 % success, 0 collisions under the shield; local vs global pose
    DAgger student of the privileged teacher: 57.8 % (worse than the shield-trained RL navigator, 76.6 %): the
    teacher's edge is privileged information the student cannot reconstruct. The same MPC on what the robot
    knows (GeoMPC(deployable=True): onboard planner's route field on the prior map, clearance from the local
    map, LIO velocity) was 85.9 % - but 50 % in 1.0 m door rooms. Isolating: true pose + true clearance 88 %,
    odometry pose + true clearance 69 %, odometry + map 50 %; zero LIO drift: 75 %.
    Root cause: the local map was built with a pose drifting relative to the world, smearing every wall by
    t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
2026-10-12 Dust outlier filter; people tracking with predictive filter checks (phase 4)
    Deployable MPC on all 13 benchmark scenarios: 80.3 % success, 4.3 % collisions; static obstacles solved
    (0 collisions in 10/13 scenarios). Weak spots: pedestrians 37.5 % collisions, dust 37.5 % timeouts, LIO lost.
    - dust: a single spurious return marked a cell occupied. Isolated-return filter on the dense scan (every
    real obstacle spans >= 2 adjacent 0.31 deg rays out to 8 m): dust 62.5 -> 100 %, thin-pole forest unchanged.
    - people: tracked from the dense LiDAR (detected when a surviving ray returns from them, 5 cm centroid noise,
    smoothed finite-difference velocity, 1 s coasting); their returns are kept out of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
2026-10-12 Safety filter: recovery from speed brakes straight
    Full benchmark forensics: the static contacts were side grazes, several while braking from 0.6-1.7 m/s
    with the recovery commanding (0, +-0.25..0.5). Admissibility checked the braking arc and the straight
    path; turning at a fixed rate while v -> 0 tightens the curve beyond both and swings the pods into what
    is beside the path. Above 0.3 m/s recovery now brakes straight. Spin-in-place measured under field
    conditions: the centre moves ~4 cm (p95 9-10 cm) in 1 s whatever the yaw rate (stationary drift, not
    spin translation). clutter/forest/rooms/mixed x 16: collisions 5 -> 1 of 64, success 87.5 %.
    Margin 0.06 instead of 0.04: 0 collisions but 7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
2026-10-12 LiDAR-odometry-loss fallback: scan-to-map registration on the dense scan
    LIO-lost scenario was 31 % success: the map was built on wheel+gyro dead reckoning (local error 0.2-0.8 m,
    up to 13 deg within a minute) and the same drifting pose was used for the prior-map route.
    Each navigation step the dense scan is now registered against the local map (grid search +-6 cm,
    +-1.5 deg around the dead-reckoned pose, mean clipped distance of returns to the mapped surfaces); the
    registered pose is a LiDAR odometry in its own right and serves as the global estimate too. Local error
    1-4 cm / < 1 deg; global 3-19 cm over 7-13 m. LIO-lost scenario: 31 -> 81 % success.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
